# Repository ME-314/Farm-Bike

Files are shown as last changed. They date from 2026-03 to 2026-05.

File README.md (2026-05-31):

# Farm-Bike
## Preamble
A simultaneous engineering project at EPFL under the *Durabilité* unit, which aims to create a modular power source for various farm machinery utilizing human work as the source of power. The development of this machine is the work of a whole semester. The project describes every step from design to machining and testing. 
<table>
  <tr>
    <td></td>
    <td></td>
  </tr>
</table>
The machine built has successfully fulfilled the requirements outlined in the subsequent paragraphs, multiple farming implements were also retrofitted to be compatible with it. Testing showed promising results and the modularity of the design proved indispensable.  

The CAD models for this project can be found in the *CadParts* folder and the manufacturing and assembly drawings in the *Drafts* folder. The *Design* section shows general design intent and is aimed at anyone wanting to recreate as similar design or better understand this one. Meanwhile the *Manufacturing* section describes the most interesting challenges faced during the fabrication of this prototype. The safe operation of machinery used requires training that this document doesn't provide. For this reason the *Manufacturing* section is not a guide and omits operations that are trivial to readers familiar with metalworking. This section is intended to provide ideas on the order of operations or fabrication techniques.  Necessary processes are specified per part to help evaluate the feasibility in accordance with available resources   

The following README contains information that may overlap with other documentation contained in the repository but is not intended as a replacement for those documents. 

<a href="https://github.com/ME-314/Farm-Bike">ME-314 Farm-Bike</a> © 2026 by Alex Baptista Coelho, Simon Dalheimer, <a href="https://github.com/FSzymans">Franciszek Szymanski</a> and Jules Taramarcaz is licensed under <a href="https://creativecommons.org/licenses/by-nc-sa/4.0/">CC BY-NC-SA 4.0</a>



## Project Video

A short video presentation of the Farm-Bike project has been published on YouTube. It shows our work atmosphere, talks about the design choices and the manufacturing process of the bike, and shows a little bit of the testing preformed at the Bassenges farm.

The video can be watched here: [Farm-Bike Project Video](https://youtu.be/_lzx3uVPyf8)

## Specification 
#### Functionality 
The Farm-Bike prototype was designed to fulfill the following main functional requirements:

- Provide a way of converting human power into useful shaft work.
- Have an easily adjustable transmission ratio.
- Allow for quick coupling with multiple machines.

In addition to these functional requirements, several quantitative design assumptions were used to dimension the prototype:

- The Farm-Bike was designed for an adult operator with a cycling cadence of `n = 70 rpm` and a continuous mechanical power input of `P = 250 W`. A considerable safety factor was also taken into consideration.
- The coupled farm machines considered during the project were assumed to operate at relatively low rotational speeds: `50–150 rpm`.
- Ergonomic parameters, such as saddle height, handlebar position, and frame geometry, were chosen to be adjustable so that users of different sizes can pedal comfortably.
#### Work Environment 
- Resist an outdoor work environment subject to a central European climate
- Resist storage in wet conditions
#### Durability
- Be built wherever possible out of standard parts to ensure long term parts availability
- Machined component to only use conventional machining to provide possibility of field repair
- Use of quality components to ensure a long life cycle  
- Easy maintenance procedures
## Design 
The design of the machine was driven by the specification outlined above and the will to ensure the project can be replicated or further developed in the future. The design choices are driven by the will to create a machine that has a long service life, quality parts and materials were chosen over low-cost alternatives.

For the final coupling between the Farm-Bike and the driven machine, a v-belt transmission was selected. This design choice provides a simple and flexible mechanical interface between the machines. Compared with a rigid shaft coupling, a belt drive is easier to install on existing agricultural machines and is more tolerant to small positioning and alignment errors. It also allows the Farm-Bike to remain mechanically independent from the driven machine, making the system easier to transport, reposition and adapt during usage. From a design point of view, the belt stage also contributes to the transmission ratio: by changing the pulley diameters, the output speed and torque can be adapted to different machines without modifying the bicycle drivetrain itself. Finally, belts and pulleys are standard, inexpensive components, which supports the project goals of repairability, modularity and long-term reproducibility.

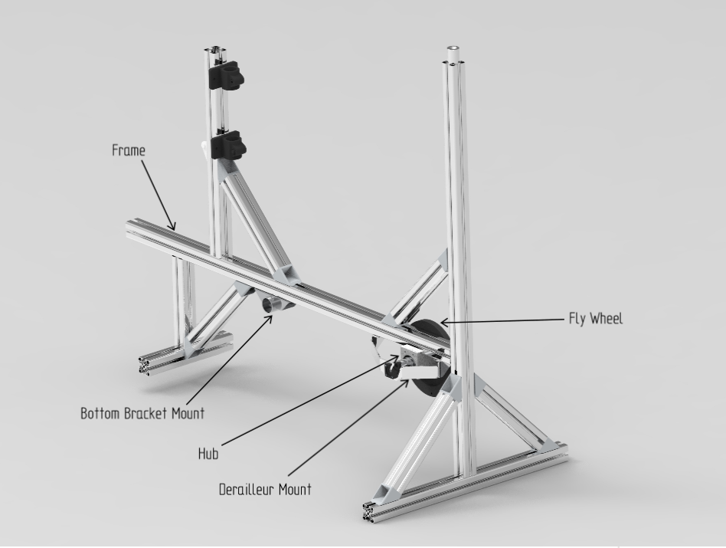
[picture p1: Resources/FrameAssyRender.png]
Render of the machine


The render above outlines the key components of the machine.
### [Frame](https://github.com/ME-314/Farm-Bike/blob/main/Drafts/FrameAssembly.pdf)
The frame is made out of Item modular aluminium extrusions, specifically the profile 8 series. This made the construction of the frame simple and required only off-the-shelf parts. The Item profile 8 can be substituted by any equivalent 40 mm $\times$ 40 mm T-slot aluminium extrusion. These dimentions correspond to a common industrial 
T-slot aluminium profile size. It was specifically chosen as a compromise between stiffness, 
weight and availability. Smaller profiles, such as 20 mm $\times$ 20 mm or 
30 mm $\times$ 30 mm, are commonly used for light frames or small mechanical 
assemblies, but would provide less bending and torsional stiffness for a structure supporting 
a seated operator and transmitting pedalling loads. Larger profiles, such as 40 mm $\times$ 80 mm 
or 80 mm $\times$ 80 mm, would increase stiffness but would also make the structure heavier, 
more expensive and less practical to handle. 

The 40 mm $\times$ 40 mm profile therefore offers a suitable intermediate solution for this 
prototype. It is widely used in modular machine frames and workstations, and it is compatible 
with standard T-slot accessories such as brackets, corner connectors, end plates and sliding 
nuts. In addition, all the aluminum profiles were recovered from the SPOT workshop at EPFL and have been used in previous projects before ours.
### Drivetrain
A transmission based on bicycle components is an optimal off-the-shelf solution to our problem. It offers robustness, ease of maintenance and worldwide availability at a low cost. The following components in the system required no modification from their retail configuration: 
- Cassette 
- Derailleur & Shifter
- Handlebars & Stem
- Crank set & Bottom Bracket
- Seat post & Saddle 

The machine is designed to be used as a modular power source for various farming implements, many of which are hand cranked and operate at around 60 rpm. Gear ratios of the bicycle drivetrain and the sizes of the pulleys were chosen in a way that allows the operator to adjust the rotational speed up and down without stopping the machine. 

The subsequent paragraph describe the design of each of the machine specific parts. The parts were designed to conform with bicycle industry standards such that commissioning and maintenance could be carried out by anyone familiar with common bicycles.

#### Gear Ratios Calculation
With the chosen cassette and chainrings and an assumed cadence of 70 rpm the output of the machine can vary between 47 and 137 rpm. If necessary the size of driven pulley mounted to the farming implement can be adjusted to suit. To simplify adapting other machinery and further development the ratio calculation spreadsheet is available in the documentation.

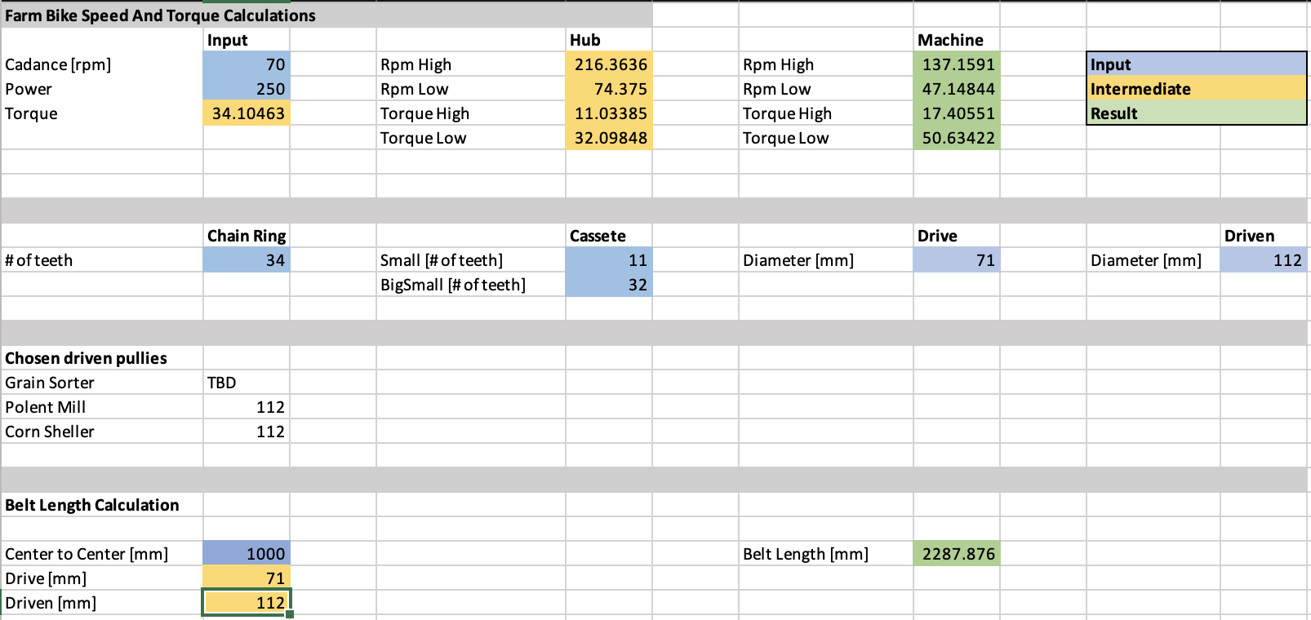
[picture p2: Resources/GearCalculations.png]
Ratio Table


For the currently selected driven pulley diameter of 112 mm, this range covers the operating speed of the polenta mill and corn sheller used during testing. In the spreadsheet you can also see a centre-to-centre distance of 1000 mm, which gives an estimated belt length of approximately 2288 mm for the 71 mm and 112 mm pulley pair.

#### Bottom Bracket Shell
The bottom bracket shell attaches the standard BSA bicycle bottom bracket to the frame. The part is a weldment of a round bottom bracket shell recovered from a donor frame and a 40 mm $\times$ 30 mm rectangular steel tube (since this part was recovered from an existing bike frame, its dimensions have not been chosen by us and were imposed by the donor frame, so standard bike components and dimensions). The part requires far less material resources than an equivalent machined from a billet and does not require specialty tooling to cut the BSA thread. By clicking this [link](https://github.com/ME-314/Farm-Bike/blob/main/Resources/BBS_removal.MOV), you can see how the part was recovered, separated from the frame and cleaned for our requirements (frame on the left of the video and BBS clamped on the table).
#### Hub
The hub forms a central part of the transmission of the machine, it mounts the cassette and the pulley thus transmits all of the power generated. A flywheel is also mounted on the axle to smooth out the power delivery.  
##### Pillow Block

This part houses the main bearings and attaches to the frame. It is a crucial part that maintains the alignment between that two bearings and ensures their long life and smooth operation, for this reason it is machined out of a 6061 Aluminium billet. Due to unavailability of appropriate stock the pillow block has been split into two pieces and pinned together. It features clearance holes for two M8 mounting bolts, a central bore for the axle to pass through and two counterbores for the 6005-2Z bearings. These deep groove ball bearings have been selected to ensure a long life span as well as being easy to source. Low-profile ball bearing often found in bicycles have specifically been discarded as their lower profile makes them more prone to premature failure. A recess has been added at the mounting between the pillow block and the aluminium profile to prevent twisting during usage.

##### Axle
The large bearings allow us to use an aluminium axle without risking the keyway becoming fragile. The axle features 25 mm bearing seats and a key way to transmit torque to the flywheel and pulley. In order to mount the cassette onto the axle while avoiding complex machining operations a donor freehub body was bonded onto the axle. The axle was of course designed around the specific freehub body available thus the design would need to be modified in accordance with available parts. 
#### Derailleur Hanger
To emulate the derailleur mounting of a conventional bicycle without having to cut a fine pitch thread a derailleur hanger from a donor frame was utilized. In order to correctly position it with respect to the axle and cassette a mount was designed out of 3mm 5005 aluminium sheet. The mount exploits the advantages of bent sheet metal to achieve a robust yet lightweight solution. 
## [Manufacturing](https://github.com/ME-314/Farm-Bike/blob/main/Drafts/FarmBikeAssembly.pdf) 
This section outlines the manufacturing processes of each of the parts and provides photos of the components. It assumes the reader is comfortable with conventional machining processes and general fabrication and thus omits the details of most trivial operations. Some parts in the assembly are overlooked in this section as their manufacturing features no operations of interest.
### [Bottom Bracket Shell](https://github.com/ME-314/Farm-Bike/blob/main/Drafts/BBMount.pdf) 
- TIG Welding
- Turning 

This is the only weldment on the machine, consisting of two parts with thin sections. The donor frame was chosen for its steel construction and BSA threaded bottom bracket. The shell was cut out and turned down to a constant diameter. During the turning operations a close fitting aluminium plug was used on the inside of the threads to provide tailstock support. The hole for the shell in the rectangular tubing was roughed out with a hole saw on a mill and fitted by hand with a file. The two parts were subsequently TIG welded and the thread was chased. TIG welding was used because of the thin material and in order to preserve as much of the BSA thread inside the shell.  

It should be noted that a farmer is not necessarily expected to have access to TIG welding equipment. A future version could therefore replace this welded part with a clamped or bolted bottom bracket support, removing the need for welding and making the design easier to reproduce with basic tools.
<table>
  <tr>
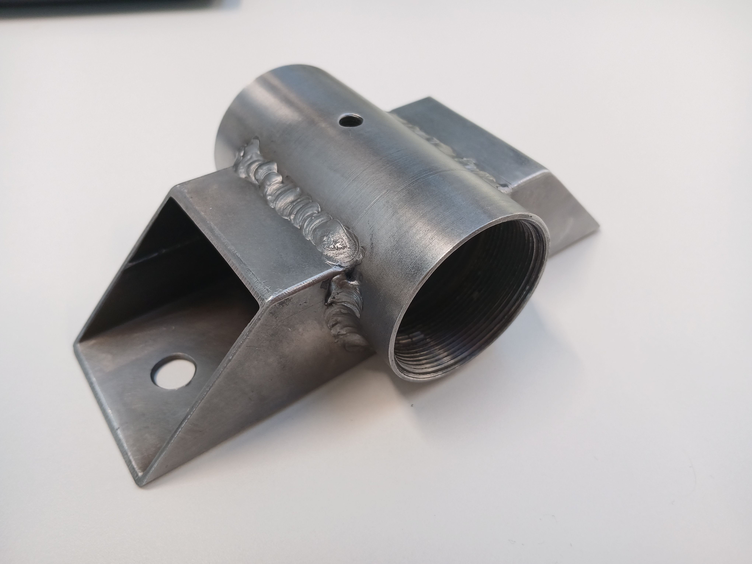
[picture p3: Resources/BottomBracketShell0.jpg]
    <td></td>
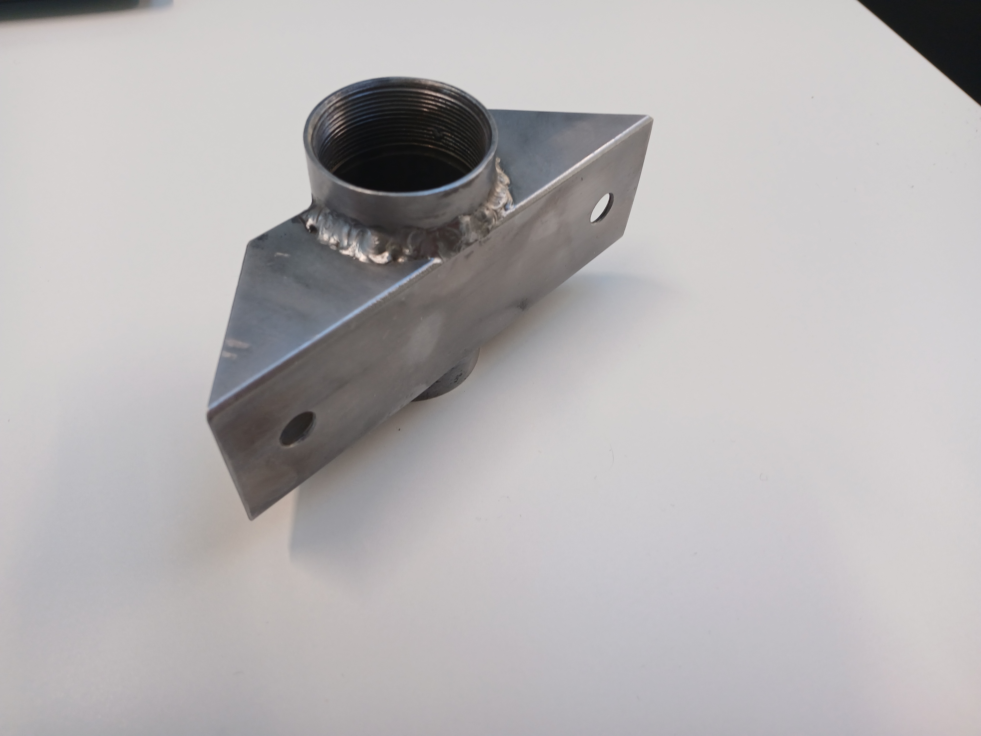
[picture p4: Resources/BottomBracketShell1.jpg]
    <td></td>
  </tr>
  <tr>
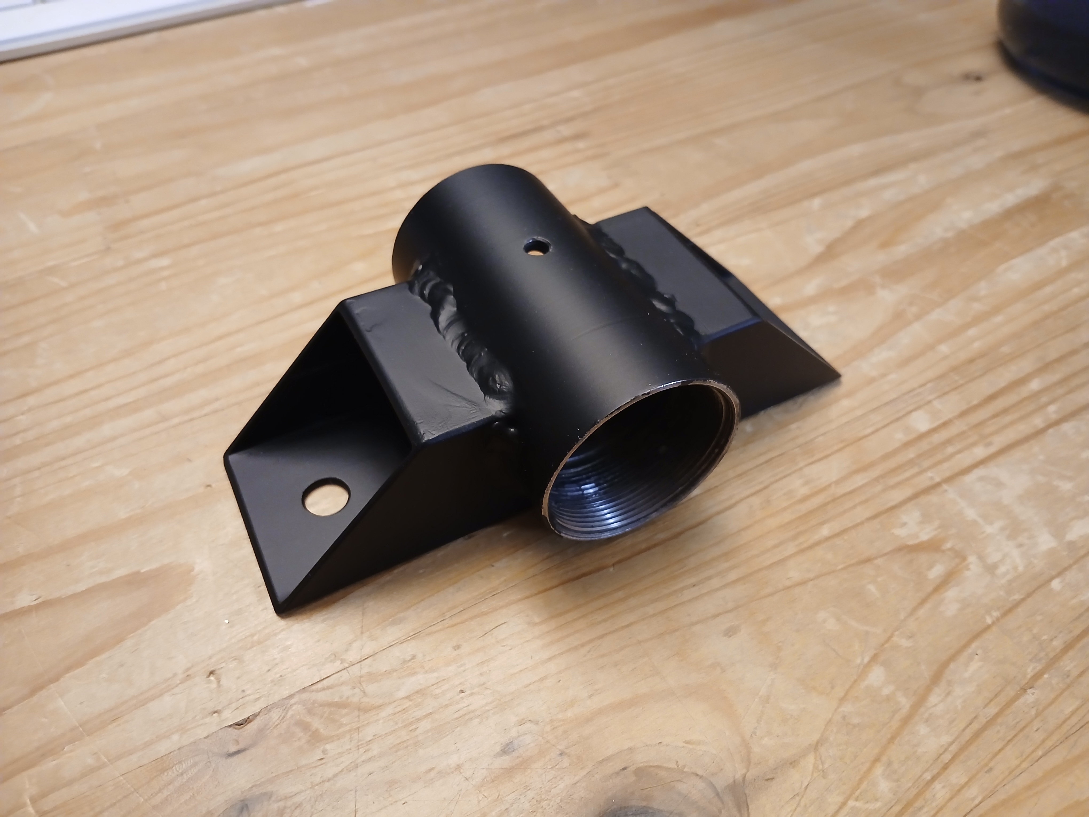
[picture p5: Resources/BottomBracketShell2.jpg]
    <td></td>
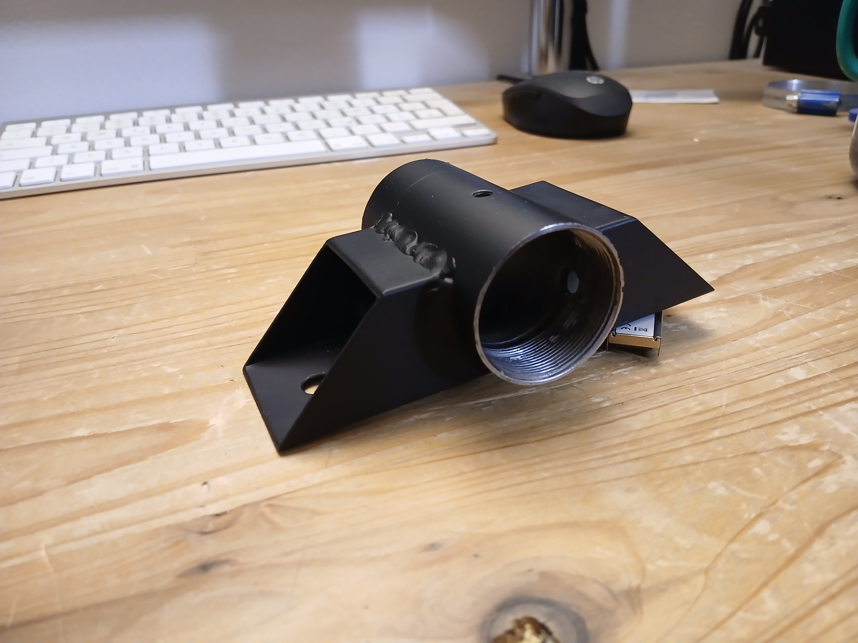
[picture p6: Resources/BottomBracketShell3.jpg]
    <td></td>
  </tr>
</table>
After welding, the oxides were removed and the part was finished with automotive anti-rust primer. 

### [Axle](https://github.com/ME-314/Farm-Bike/blob/main/Drafts/DriveAxle.pdf)
- Turning 
- Milling

The machining operations did not deviate from standard practice. Loctite 603 retaining compound was used to chemically bond the freehub body to the axle. Chemical bonding was chosen to remove the need for pressing in the axle thus eliminating the risk of fracture on the hardened freehub body. 
### [Pillow Block](https://github.com/ME-314/Farm-Bike/blob/main/Drafts/PillowBlock.pdf)
- Turning 
- Milling
Due to limitations in the available stock material the pillow block was machined from two separate pieces of stock.

Watch the video

The operations were carried out in the following order: 
- Squaring the stock to size 
- Drilling and reaming of the 4mm pin bores
- Centre drilling of the main bore
- Two parts are pressed together 
- Milling locating slot 
- Drilling of two M8 clearance holes
- Boring half of the through bore in a lathe with centre drill hole as reference
- Boring of bearing seat
- Part flipped and boring operations repeated
- Deburring and chamfering 

<table>
  <tr>
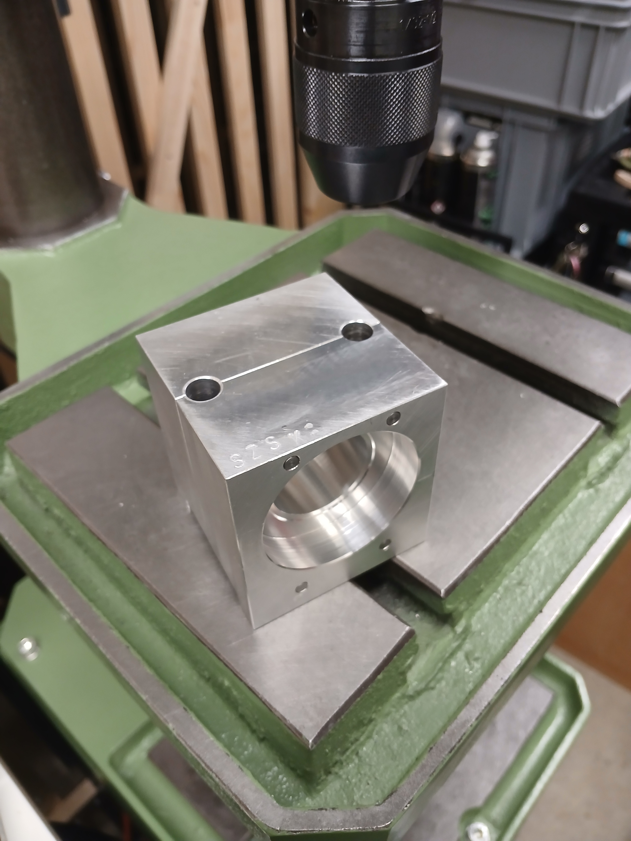
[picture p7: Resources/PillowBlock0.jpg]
    <td></td>
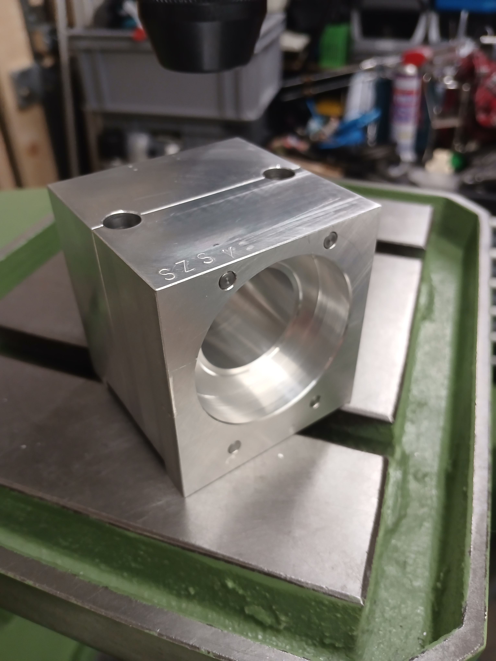
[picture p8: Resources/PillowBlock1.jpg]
    <td></td>
  </tr>
  <tr>
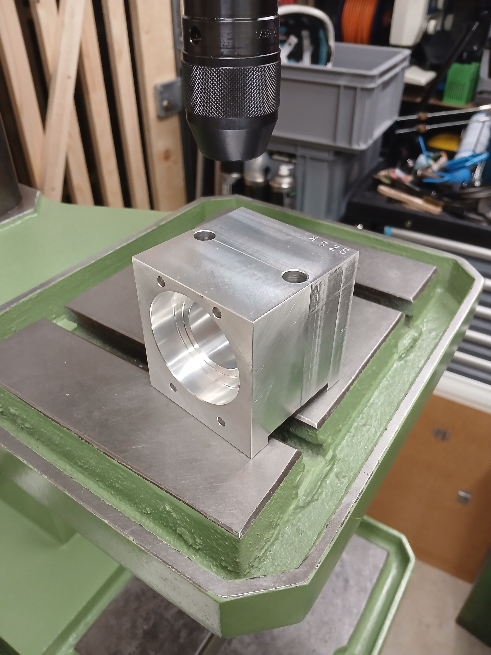
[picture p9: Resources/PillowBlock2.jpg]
    <td></td>
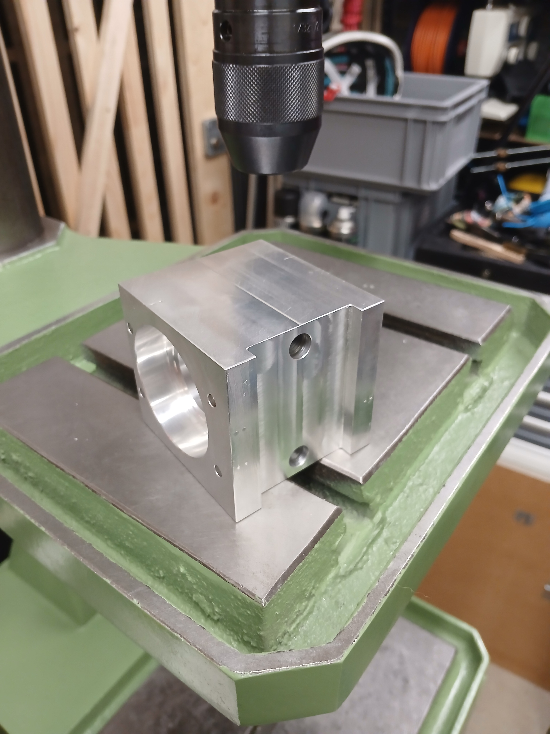
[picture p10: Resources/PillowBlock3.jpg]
    <td></td>
  </tr>
</table>
Following machining, deburring and finishing was carried out and the bearings were fitted

### [Fly Wheel](https://github.com/ME-314/Farm-Bike/blob/main/Drafts/FlyWheelAssyDrawing.pdf)
- Turning 
- If available fibre laser cutting or water jet

In order to avoid procuring costly stock material the fly wheel is cut out of 5 mm S235 structural steel (a bit pedantic of a designation, we know, but what is life without whimsy) and the pieces are pinned together. The use of a fibre laser allows for significant time saving but all of the parts can be machined using conventional processes. Our parts were pressed together with an arbor press and a coat of anti-rust primer protects against corrosion. Since the flywheel geometry is relatively simple, the plates could also be manufactured using more accessible workshop methods: drilling combined with sawing, or even manual cutting followed by filing and balancing.
<table>
  <tr>
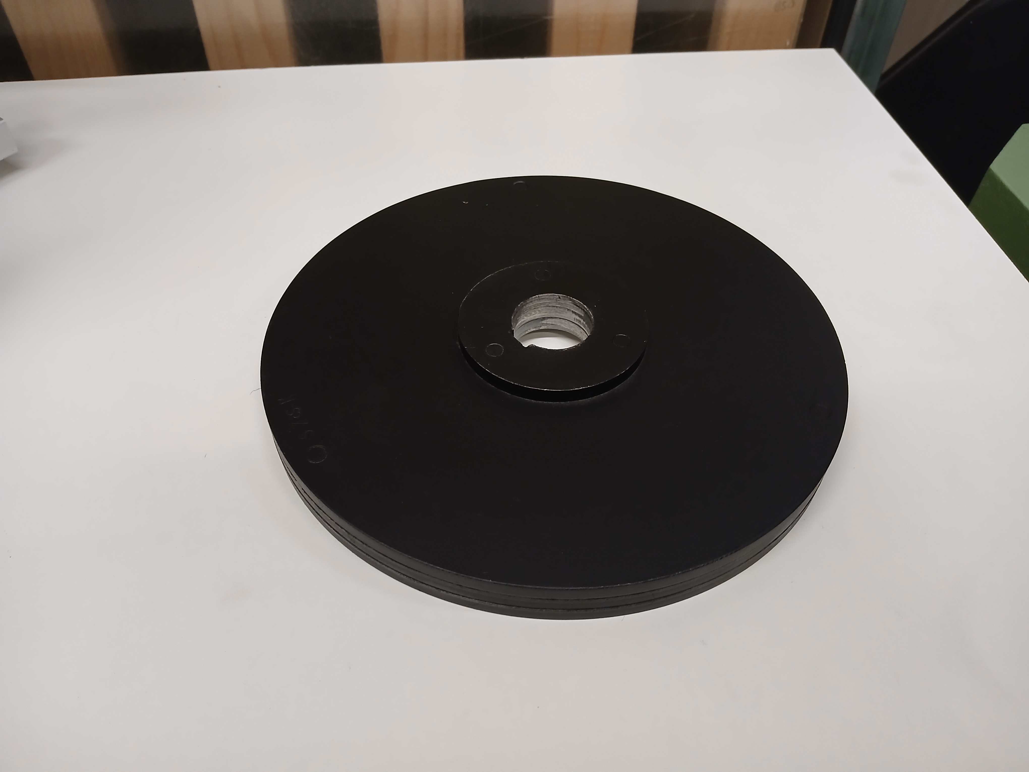
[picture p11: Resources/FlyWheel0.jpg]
    <td></td>
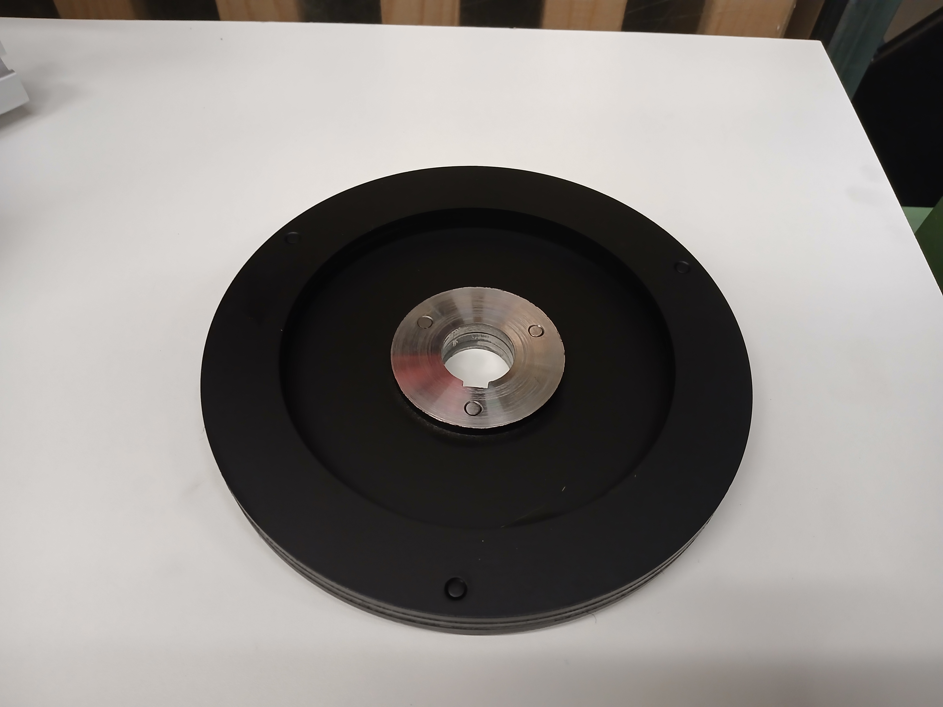
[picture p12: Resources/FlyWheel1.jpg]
    <td></td>
  </tr>
</table>

### [Hub](https://github.com/ME-314/Farm-Bike/blob/main/Drafts/HubExploded.pdf) 
Precaution taken during assembly of the hub:
- Parts cleaned and lubricated 
- Light preload applied to the bearings 
- Taper lock pulley and bushing torqued to manufacturer specification

<table>
  <tr>
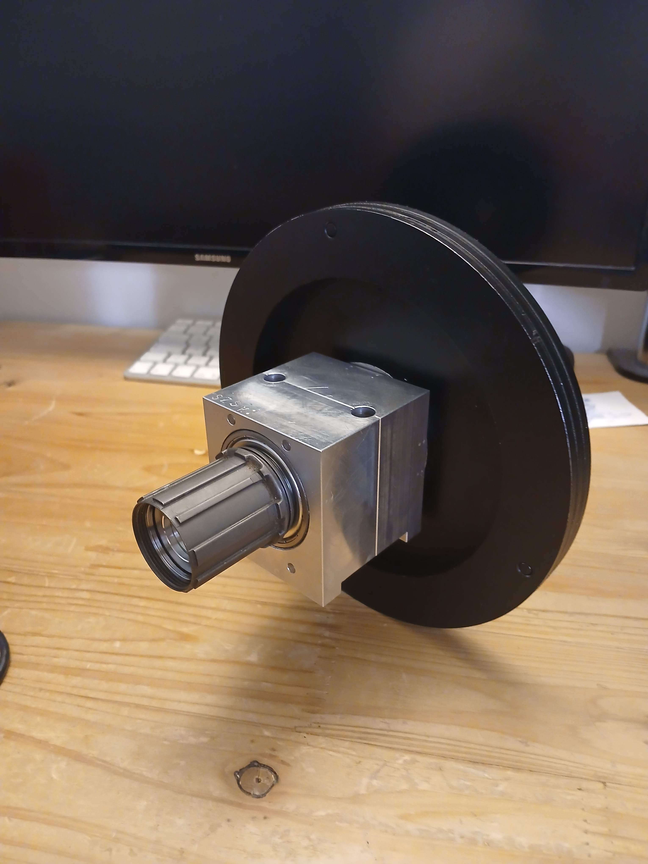
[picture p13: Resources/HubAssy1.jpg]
    <td></td>
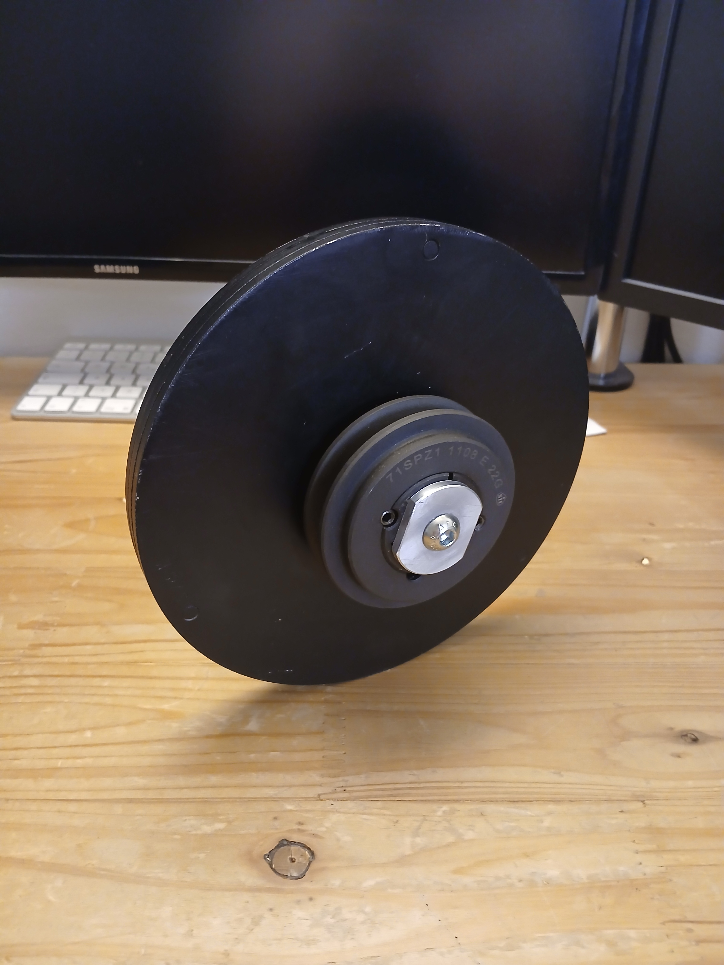
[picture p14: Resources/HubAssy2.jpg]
    <td></td>
  </tr>
</table> 

### [Derailleur Mount](https://github.com/ME-314/Farm-Bike/blob/main/Drafts/DerailleurBracketDrawing.pdf) 
- Metal Cutting
- Sheet Metal Bending
- If available fibre laser cutting or water jet

Just like the fly wheel the derailleur mount was cut with the use of a fibre laser. Due to its non-trivial geometry the sheet metal part was bent in a bench vice with the help of parallel jaw pliers. The existing derailleur hanger was hand fitted during the finishing process. As most of the part geometries are non mating surfaces the part could be replicated with hand tools. The geometry can be modified to suit the manufacturing methods available.
<table>
  <tr>
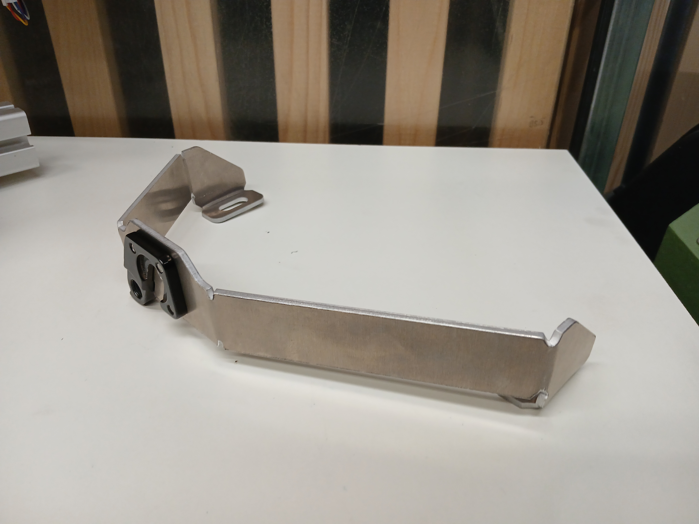
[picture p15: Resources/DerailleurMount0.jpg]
    <td></td>
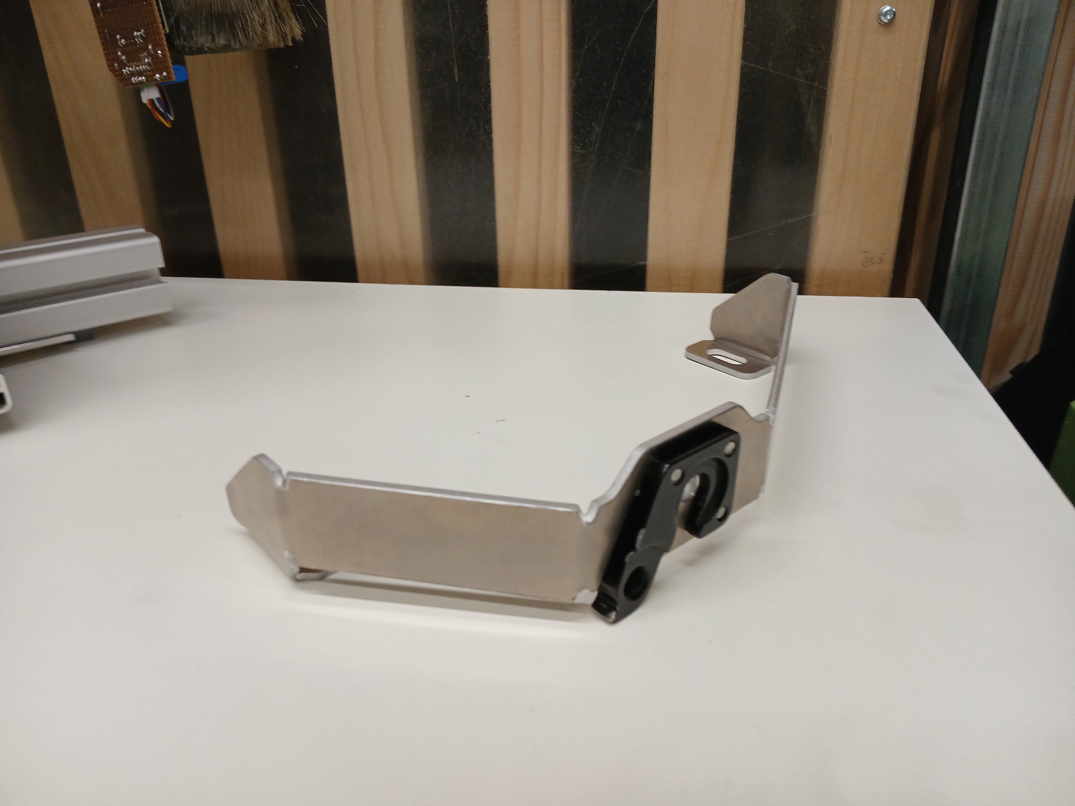
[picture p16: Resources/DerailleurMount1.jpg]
    <td></td>
  </tr>
  <tr>
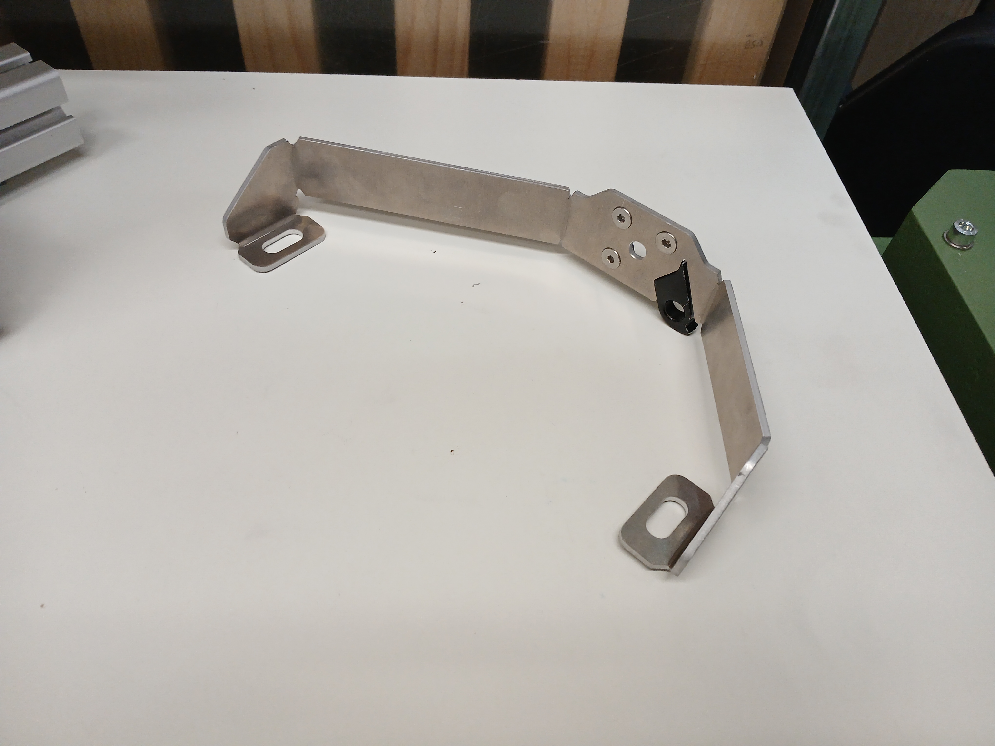
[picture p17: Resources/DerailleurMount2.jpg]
    <td></td>
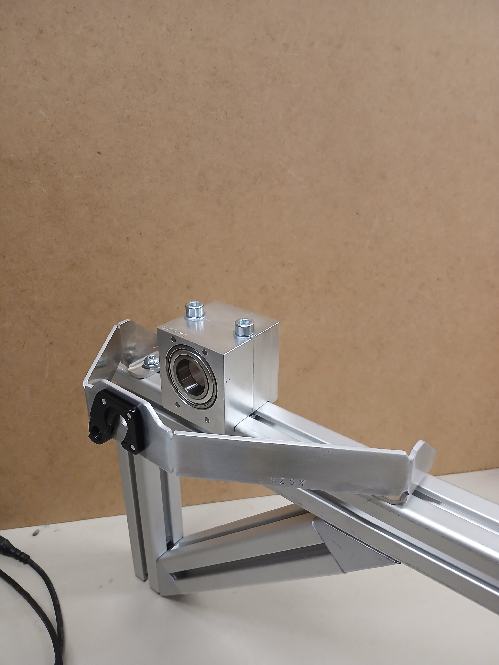
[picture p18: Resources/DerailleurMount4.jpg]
    <td></td>
  </tr>
</table> 

## Procurement Guide 
Normalized industrial parts for this project can be commonly bought new from well established suppliers. The parts for the prototype were sourced from [Norelem](https://www.norelem.ch/), but equivalent parts can be sourced from: 
- [Misumi](https://fr.misumi-ec.com/)
- [RS Components](https://us.rs-online.com/)
- [McMaster-Carr](https://www.mcmaster.com/)
- [JLCMC](https://jlcmc.com/)
In this project the part numbers specified on assembly drawings and in the cad model correspond to Norelem part numbers.  
To reduce the ecological impact of the prototype, second hand or recovered components were utilized in areas that would not impact the longevity, safety or operation of the machine.
Item aluminium profiles and relevant hardware were recovered from decommissioned machinery. Equivalents can be sourced from the suppliers above or Item24 directly. Wherever possible material off-cuts or scrapped parts we used as stock material.   
Bicycle components for the prototype were second hand and sourced from *Point Vélo* located on the EPFL campus.

## Prototype Overview

After the design and manufacturing phases, the **Farm-Bike prototype** was fully assembled.

The image below shows the assembled Farm-Bike prototype in its final pre-testing configuration. It highlights the complete mechanical structure, including the aluminium frame, the bicycle transmission, the rear wheel 10-speed cassette, the pedals, and the operator interface.

<p align="center">
  Assembled Farm-Bike prototype in pre-testing configuration
</p>

<p align="center">
  <em>Assembled Farm-Bike prototype.</em>
</p>

This final assembly represents the functional outcome of the project and serves as the basis for future improvements, such as ergonomic optimisation, stronger machine coupling, and further field testing at the farm.

## User Guide 

### Use Instructions 
Before operating the machine, ensure that it is placed on a stable and level surface. The frame should not rock or move under load, and all fasteners securing the aluminium profiles, pillow block, bottom bracket shell, seat post and handlebar assembly should be checked for tightness. The pulley, flywheel and cassette should be visually inspected to ensure that they are correctly seated and that no foreign object is interfering with the drivetrain.

The user should adjust the saddle height and handlebar position to obtain a comfortable pedalling position. As with a conventional bicycle, the saddle height should allow the leg to remain slightly bent at the bottom of the pedal stroke. The drivetrain can then be shifted using the standard bicycle shifter in order to select the desired transmission ratio. The rear derailleur can be shifted using the standard handlebar shifter, while the front chainring selection has to be carried out manually. The user should therefore stop pedalling, wait for the drivetrain to come to rest, and move the chain by hand only when the machine is fully stationary. This should be done by getting off the bike, adjusting the chain to the desired chainring setting and gently cranking the pedals by hand such that the chain jumps into its desired place. The user can afterwards get back onto the bike and pedal normally. Lower gears should be used when starting the machine or when driving a high-load implement, while higher gears can be used once the system is already rotating smoothly or when a higher output speed is required.

To start the machine, the user should begin pedalling progressively and avoid sudden impacts on the pedals. The flywheel will gradually store kinetic energy and smooth out the power delivery. Once the machine is rotating steadily, the selected gear ratio can be adjusted depending on the required output speed and the resistance of the coupled machine. Gear changes should preferably be carried out while pedalling with moderate force, in the same way as on a standard bicycle, in order to avoid excessive stress on the chain and derailleur.

Before coupling the Farm-Bike to an external machine, the user must ensure that the driven machine is compatible with the output speed, torque and rotation direction of the system. The coupling should be securely mounted and aligned with the pulley or output shaft to avoid vibrations, belt slipping or premature wear. During operation, hands, clothing and loose objects must be kept away from the chain, cassette, pulley, flywheel and any rotating element.

To stop the machine, the user should simply reduce pedalling effort progressively and allow the drivetrain and flywheel to slow down naturally. The user should not attempt to stop the flywheel, pulley or chain by hand. After use, the machine should be inspected for loose fasteners, abnormal noise, chain misalignment or signs of wear. If the machine has been used outdoors or stored in humid conditions, exposed steel parts should be dried and checked for corrosion.

### Maintenance Guide 
Time intervals for preventative maintenance intervals are guidelines, maintenance intervals should be adjusted in accordance with conditions of use and storage. 
- each use inspect fasteners and drivetrain
- 7-10h clean and lubricate chain
- 30-50h degrease and lubricate chain
- 100h inspect drivetrain for wear
- 150h disassemble and inspect hub and crank set

Parts deemed inoperable during inspection are to be replaced 

For a more detailed explanation on fitting adjusting and maintaining bicycle specific components please refer to General Operations Manual *(ref:DM-GN0001)* published by Shimano.

### Troubleshooting Guide  

| Issue | Likely cause | Corrective action |
|---|---|---|
| Unusual noise | Loose fastener | Verify and tighten fasteners. |
| Chain skips under power | Worn drivetrain components | Replace the chain. If the issue persists, replace the cassette and chainrings. |
| Chain jumps between gears | Shifting not adjusted | Adjust the shift cable. |
| Chain falls off the top or bottom of the cassette | Derailleur limits out of adjustment | Adjust the derailleur limits. |
| Excessive friction in drivetrain under no load | Debris stuck or tangled in the drivetrain | Inspect the drivetrain and remove debris. |

## Testing 

### Initial Testing

The first functional test was carried out directly at the Bassenges farm. The Farm-Bike prototype was brought to the farm and connected to two existing machines: the polenta grinder and the corn sheller. Pulleys were installed on both machines, after which the bike was coupled to the system and tested. The first test was successful, as the Farm-Bike was able to drive the machines through the belt transmission. The whole Bassenges team was present during the test.

However, once the system was operating, an important ergonomic issue was identified by Timothée, the farmer responsible for following the project at the Bassenges farm. In the initial configuration, the bike was not facing the machines. This meant that a single operator could not comfortably pedal the bike and load the machines at the same time. This feedback highlighted an important practical limitation of the first assembly.

After considering the problem, we realized that the modular aluminium profile frame made it possible to rearrange the bike without manufacturing new parts. Several components were repositioned so that the pulley attachment faced the opposite direction and was located at the front of the bike. This allowed the Farm-Bike to be adapted directly to the farmer's request. Due to the lack of equipment at the farm, we were not able to reduce the length of the chain, which is planned for the following week.

Initial testing confirmed the value of using modular aluminium profiles for the frame. The ability to modify the geometry of the machine on site was a major advantage during the testing phase. If the frame had been fully welded or made as a fixed steel structure, this last-minute correction would not have been possible without significant rework.

The following images show the Farm-Bike before and after the reassembly:

<table>
  <tr>
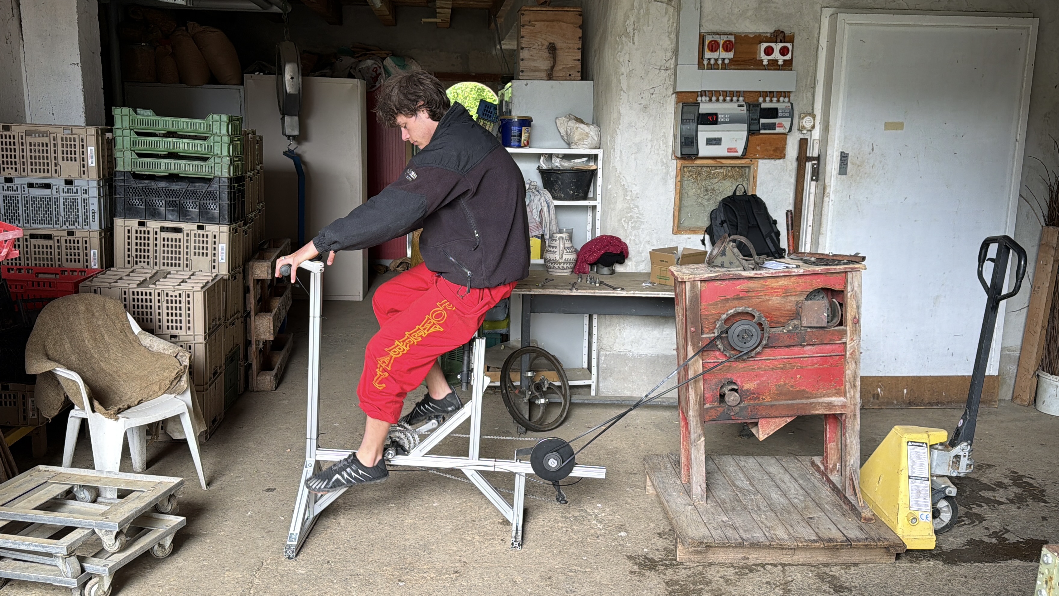
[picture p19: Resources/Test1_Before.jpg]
    <td></td>
    <td></td>
  </tr>
  <tr>
    <td align="center"><em>Initial configuration</em></td>
    <td align="center"><em>Modified configuration</em></td>
  </tr>
</table>

### Second Testing Session

The second day of testing allowed the team to further adapt the **Farm-Bike prototype** based on the observations made during the first trial.

In particular, the chain length was adjusted and the seating position was modified accordingly. The overall design proved to be functional; however, the shortening of the chain had an effect on the shifting performance. Gear changes became less smooth than before, and the most extreme gear-ratio settings became more difficult to use.

Another important feedback point was given by **Timothée**, who suggested keeping the inertial wheel attached to the corn sheller. In response to this, the pulley transmission was modified. Instead of removing the inertial wheel, the pulley system was attached to the rear side of the transmission axle, replacing an old unused gear. This allowed the inertial wheel to be reinstalled on the machine while still maintaining the connection between the Farm-Bike and the corn sheller.

The following day, the team returned to the farm to make additional ergonomic and functional improvements. The shifting cable was shortened, and the stem was lengthened in order to improve both the shifting accessibility and the seating position. These modifications made the system more comfortable to operate and better adapted to the user during testing.

The image below shows the Farm-Bike connected to the corn sheller during the testing phase.

<p align="center">
  Farm-Bike prototype connected to the corn sheller during testing
</p>

<p align="center">
  <em>Farm-Bike prototype connected to the corn sheller during testing.</em>
</p>

### Last Testing Session

During the final week of testing, an interview was conducted with Timothée as part of the video presentation of the project. The discussion focused on his feedback regarding the Farm-Bike prototype, his impression of the proposed solution for driving the machines, and the possible improvements he suggested for future iterations.

One improvement mentioned by Timothée was to make the system compatible with flat belts. This suggestion was based on the fact that many agricultural machines from the early twentieth century were originally designed to be driven by flat belts. In addition, flat belts can be easier to manufacture or repair locally, for example from leather or other flexible materials that can be cut to the required width and length.

During this final testing phase, a third pulley system was also installed on a grain sorter. This machine was different from the agricultural machines analyzed previously, which allowed the adaptability of the Farm-Bike concept to be further evaluated.

Here is the grain sorting machine shown below. This machine already includes a mechanical transmission system, making it suitable for coupling through an external belt drive.

<p align="center">
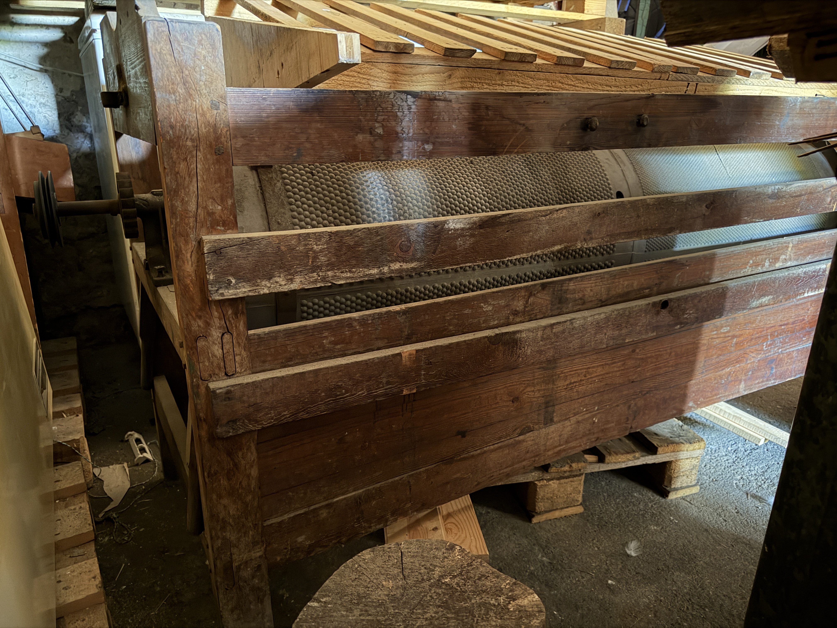
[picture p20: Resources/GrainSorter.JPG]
General view of the grain sorting machine
  
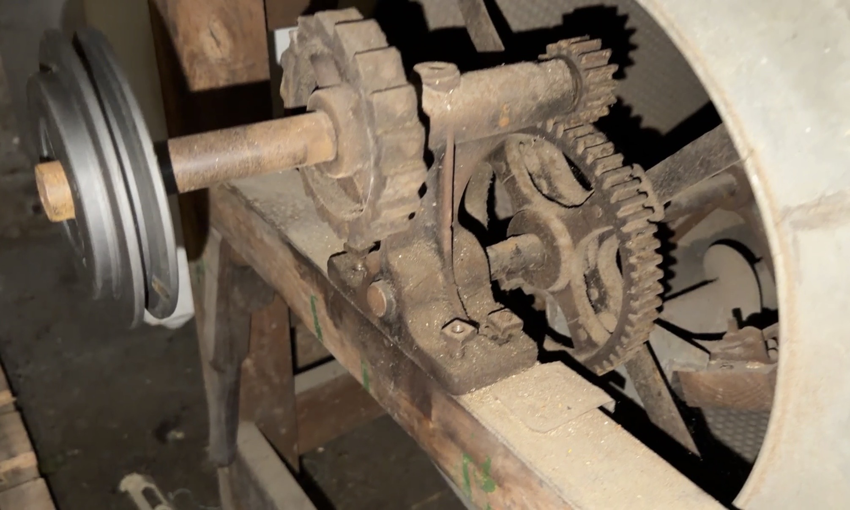
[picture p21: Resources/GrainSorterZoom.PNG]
Close-up view of the pulley and gear mechanism
  
</p>

<p align="center">
  <em>Existing grain sorting machine and close-up view of its pulley and gear transmission mechanism.</em>
</p>

## Conclusion & Future Improvements

A future improvement identified during the final testing phase would be to make the Farm-Bike compatible with flat belt transmissions. Timothée pointed out that many older agricultural machines, were originally designed to be driven by flat belts. Adding this compatibility would therefore increase the number of machines that could be powered by the Farm-Bike, especially in the context of farms using older or restored equipment.

This improvement would require the development of an alternative output pulley system designed specifically for flat belts. The pulley geometry, belt tensioning method and alignment system would need to be adapted, since flat belts are more sensitive to lateral misalignment than V-belts. However, this solution would also improve the repairability and local reproducibility of the system, as flat belts can be manufactured or repaired more easily from simple flexible materials, such as leather or rubber strips cut to the required width and length.

More generally, this feedback shows that future development should focus not only on the Farm-Bike itself, but also on the compatibility between the bike and a wider range of agricultural machines. A modular output interface, with interchangeable pulleys for V-belts and flat belts, would make the system more versatile and better adapted to real farm conditions.

## List of Components & Costs

### STEP Assembly File Component List

The following table lists the main components from the `FarmBike.stp` assembly with the respective names used.

| Quantity | Component name |
|---:|---|
| 10 | 45Joint |
| 6 | FrontSupport |
| 2 | TubeClampMount |
| 2 | 6005-2Z bearing |
| 2 | PillowBlock |
| 2 | 29014-30 |
| 2 | FlyWheelMass |
| 2 | FlyWheelSpacer |
| 1 | HeadTube |
| 1 | MainFrame |
| 1 | 23200-0382522 |
| 1 | 22070-12711 |
| 1 | FreeHubBody |
| 1 | FrontLeg |
| 1 | DerailleurBracket |
| 1 | 27616-08095 |
| 1 | StemMount |
| 1 | BackSupport |
| 1 | BottomBracketMount |
| 1 | BottomBracketShell |
| 1 | FilletWeld_1 |
| 1 | DerailleurHanger.psm |
| 1 | SeatTube |
| 1 | FlyWheel |
| 1 | DriveAxle |
| 1 | DummyBearing |

### Aluminium Profile Cut List

The main frame is made from 40 × 40 mm aluminium profile. The total required profile length is approximately **4.96 m**.

| Quantity | Component | Profile type | Length per part | Total length |
|---:|---|---|---:|---:|
| 1 | HeadTube | 40 × 40 mm aluminium profile | 1000 mm | 1000 mm |
| 1 | MainFrame | 40 × 40 mm aluminium profile | 1160 mm | 1160 mm |
| 6 | FrontSupport | 40 × 40 mm aluminium profile | 250 mm | 1500 mm |
| 1 | FrontLeg | 40 × 40 mm aluminium profile | 580 mm | 580 mm |
| 1 | BackSupport | 40 × 40 mm aluminium profile | 220 mm | 220 mm |
| 1 | SeatTube | 40 × 40 mm aluminium profile | 500 mm | 500 mm |
|  | **Total** |  |  | **4960 mm** |

### Components Purchased from Point Vélo

The following bicycle components were purchased from Point Vélo and used for the Farm-Bike drivetrain and rider interface.

| Quantity | Component |
|---:|---|
| 1 | 10-speed cassette |
| 1 | Pair of pedals |
| 1 | 3-speed chainring / crankset |
| 1 | Rear derailleur |
| 1 | Saddle |
| 1 | Seatpost |
| 1 | Stem |
| 1 | Handlebars |
| 1 | Bottom bracket shell |
| 1 | 10-speed compatible chain |
| 1 | Rear derailleur shifter |
| 1 | Set of shifter cables |

### Farm-Bike Budget Sheet — Confirmed Purchases

<p align="center">
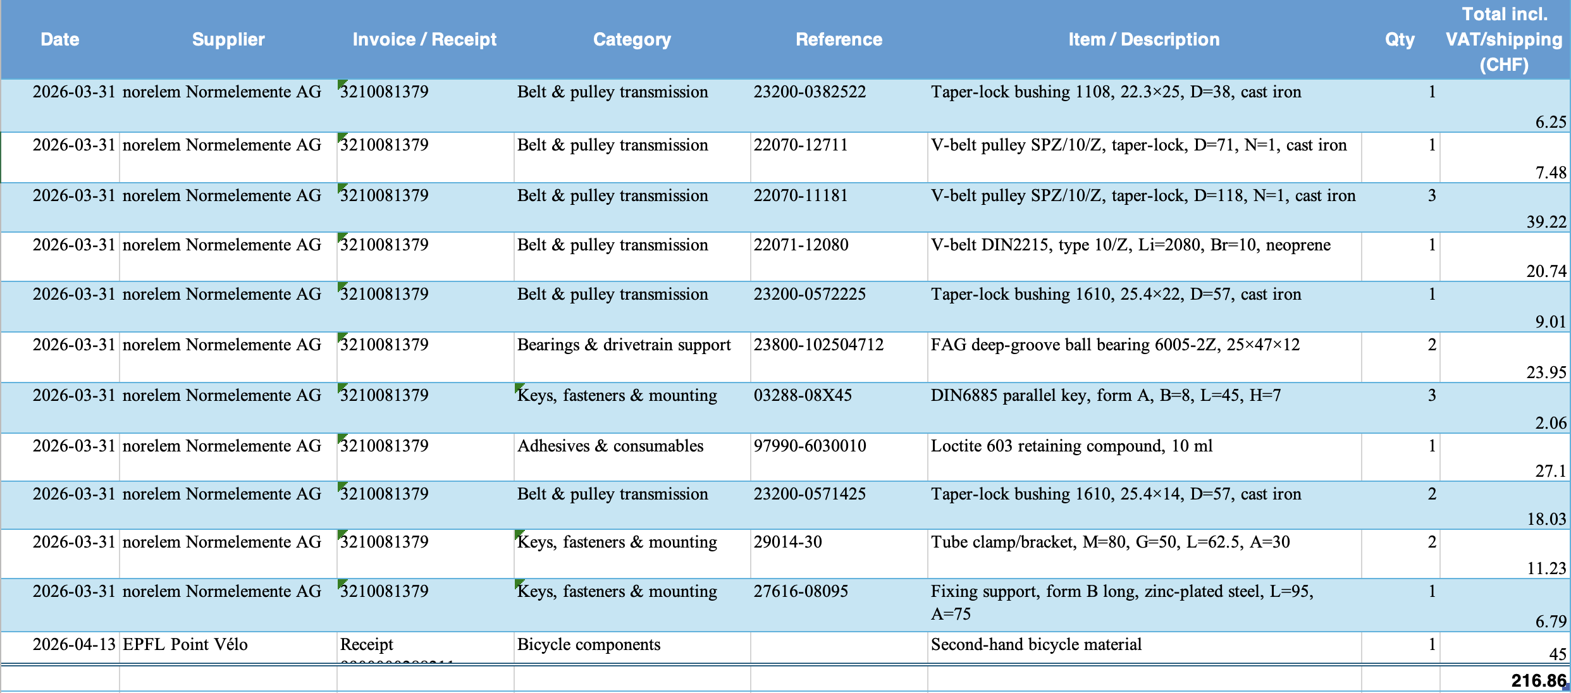
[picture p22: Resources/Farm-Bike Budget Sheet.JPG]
Confirmed purchases included in the Farm-Bike budget sheet, summarising the cost of the components bought.
  
</p>

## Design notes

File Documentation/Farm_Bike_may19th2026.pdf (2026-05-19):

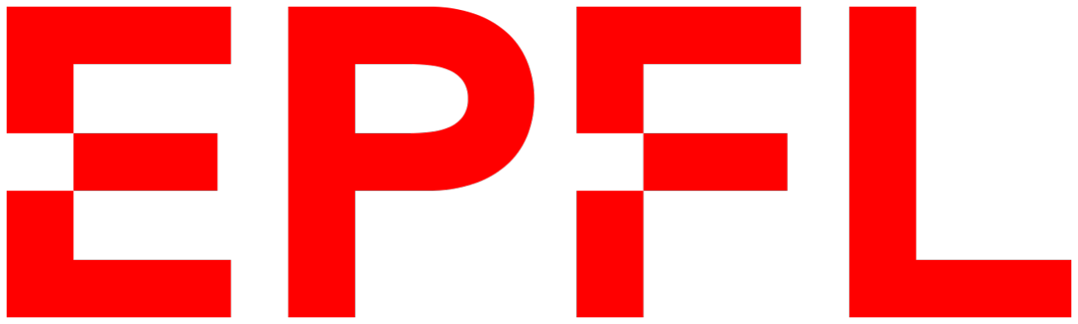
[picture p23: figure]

École Polytechnique Fédérale de Lausanne

# Farm-Bike

Simultaneous Engineering Project

ME-314 Coursework

ME-314 Project Team

May 19, 2026

# Contents

1 Preamble | 1
2 Specification | 2
3 Design | 3
4 Manufacturing | 6
5 Procurement Guide | 10
6 User Guide | 11
7 Testing | 13
A Technical Drawing Annex | 14

i

Farm-Bike | ME-314

ii

# Chapter 1

# Preamble

A simultaneous engineering project at EPFL under the Durabilité unit, which aims to create a modular power source for various farm machinery utilizing human work as the source of power. The development of this machine was the subject of a simultaneous engineering project, course code ME-314, and is the work of a whole semester. The project describes every step from design to machining and testing.

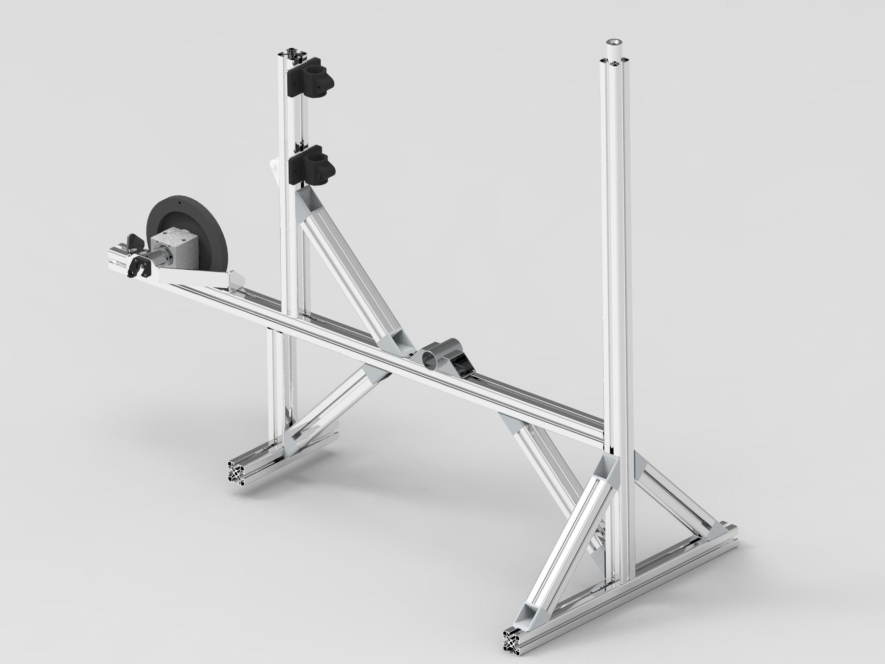
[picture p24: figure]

Figure 1.1: Render of the machine.

The following README contains information that may overlap with other documentation contained in the repository but is not a replacement for those documents.

# Chapter 2

# Specification

### 2.1 Functionality

- Provide a way of converting human power into useful shaft work.
- Have easily adjustable transmission ratio.
- Allow for quick coupling of multiple machines.

### 2.2 Work Environment

- Resist an outdoor work environment subject to a central European climate.
- Resist storage in wet conditions.

### 2.3 Durability

- Be built wherever possible out of standard parts to ensure long term parts availability.
- Machined components to only use conventional machining to provide possibility of field repair.
- Use of quality components to ensure a long life cycle.
- Easy maintenance procedures.

# Chapter 3

# Design

The design of the machine was driven by the specification outlined above and the will to ensure the project can be replicated or further developed in the future. The design choices are driven by the will to create a machine that has a long service life, quality parts and material were chosen over low-cost alternatives.

### 3.1 Frame

The frame is made out of Item modular aluminium extrusions, specifically the profile 8 series. This made the construction of the frame simple and required only off-the-shelf parts. The Item profile 8 can be substituted by any equivalent 40 mm × 40 mm T-slot aluminium extrusion. The choice of aluminium extrusion was made to ensure availability of materials in any geographical region as well as ensure repairability, the ease of manufacture was of course a welcome bonus.

### 3.2 Drivetrain

A transmission based on bicycle components is the optimal off-the-shelf solution to our problem. It offers robustness, ease of maintenance and worldwide availability at a low cost. The following components in the system required no modification from their retail configuration:

- Cassette.
- Derailleur & Shifter.
- Handlebars & Stem.
- Crank set & Bottom Bracket.
- Seat post & Saddle.

The machine is designed to be used as a modular power source for farming implements, many of which are hand-cranked and operate around 60 rpm. The bicycle drivetrain and pulley dimensions were selected so that the operator can adjust the rotational speed without stopping the machine. With the chosen cassette, chainring and pulley diameters, and for an assumed pedalling cadence of 70 rpm, the machine output can vary between approximately 47 rpm and 137 rpm. If another farming implement requires a different speed range, the driven pulley diameter can be changed accordingly.

### 3.3 Gear Ratios and Speed Calculations

The speed calculations are present on the spreadsheet included in the GitHub repository under Documentation/FarmBikeSpeedCalc.xlsx. The assumed rider input is a cadence of 70 rpm and a mechanical power of 250 W. The crank torque is therefore calculated as

Tcrank =

P 60
n 2π

= 34.10 N m.

The high-speed case uses the smallest cassette sprocket, while the low-speed case uses the largest cassette sprocket. The final pulley stage uses a 71 mm drive pulley and a 112 mm driven pulley.

Table 3.1: Gear ratio, speed and torque calculations for the Farm-Bike drivetrain.

Parameter | High-speed setting | Low-speed setting
Chainring teeth | 34 | 34
Cassette sprocket teeth | 11 | 32
Bicycle | drivetrain | ratio | ichain | =

Nchainring/Ncassette

3.09 | 1.06
Hub speed at 70 rpm cadence [rpm] | 216.36 | 74.38
Hub torque for 250 W input [N m] | 11.03 | 32.09
Drive pulley diameter [mm] | 71 | 71
Driven pulley diameter [mm] | 112 | 112
Pulley ratio ipulley = Ddrive/Ddriven | 0.63 | 0.63
Overall speed ratio itot = ichainipulley | 1.96 | 0.67
Machine output speed [rpm] | 137.16 | 47.15
Machine output torque [N m] | 17.40 | 50.63

For the currently selected driven pulley diameter of 112 mm, this range covers the operating speed of the polenta mill and corn sheller used during testing. In the spreadsheet you can also see a centre-to-centre distance of 1000 mm, which gives an estimated belt length of approximately 2288 mm for the 71 mm and 112 mm pulley pair.
The subsequent paragraphs describe the design of each of the machine-specific parts. The parts were designed to conform with bicycle industry standards such that commissioning and maintenance could be carried out by anyone familiar with common bicycles.

### 3.3.1 Bottom Bracket Shell

The bottom bracket shell attaches the standard BSA bicycle bottom bracket to the frame. The part is a weldment of a round bottom bracket shell recovered from a donor frame and a 40 mm × 30 mm rectangular steel tube. The part requires far less material resources than an equivalent machined from a billet and does not require specialty tooling to cut the BSA thread.

### 3.3.2 Hub

The hub forms a central part of the transmission of the machine, it mounts the cassette and the pulley thus transmitting all of the power generated. A flywheel is also mounted on the axle to smooth out the power delivery.

### 3.3.3 Pillow Block

This part houses the main bearings and attaches to the frame. It is a crucial part that maintains the alignment between the two bearings and ensures their long life and smooth operation, for this reason it is machined out of a 6061 aluminium billet. Due to unavailability of appropriate stock the pillow block has been split into two pieces and pinned together. It features clearance holes for two M8 mounting bolts, a central bore for the axle to pass through and two counterbores for the 6005-2Z bearings. These deep groove ball bearings have been selected to ensure a long life span as well being easy to source. Low profile ball bearings often found in bicycles have specifically been discarded as their lower profile makes them more prone to premature failure. A recess has been added at the mounting between the pillow block and the aluminium profile to prevent twisting during usage.

### 3.3.4 Axle

The large bearings allow us to use an aluminium axle without risking the keyway becoming fragile. The axle features 25 mm bearing seats and a key way to transmit torque to the flywheel and pulley. In order to mount the cassette onto the axle while avoiding complex machining operations a donor freehub body was bonded onto the axle. The axle was of course designed around the specific freehub body available thus the design would need to be modified in accordance with available parts.

### 3.3.5 Derailleur Hanger

To emulate the derailleur mounting of a conventional bicycle without having to cut a fine pitch thread a derailleur hanger from a donor frame was utilized. In order to correctly position it with respect to the axle and cassette a mount was designed out of 3 mm 5005 aluminium sheet. The mount exploits the advantages of bent sheet metal to achieve a robust yet lightweight solution.

# Chapter 4

# Manufacturing

This section outlines the manufacturing processes of each of the parts and provides photos of the components. It assumes the reader is comfortable with conventional machining processes and general fabrication and thus omits the details of most trivial operations. Some parts in the assembly are overlooked in this section as their manufacturing features no operations of interest.

### 4.1 Bottom Bracket Shell

This is the only weldment on the machine, consisting of two parts with thin sections. The donor frame was chosen for its steel construction and BSA threaded bottom bracket. The shell was cut out and turned down to a constant diameter. During the turning operations a close fitting aluminium plug was used on the inside of the threads to provide tailstock support. The hole for the shell in the rectangular tubing was roughed out with a hole saw on a mill and fitted by hand with a file. The two parts were subsequently TIG welded and the thread was chased. TIG welding was used because of the thin material and in order to preserve as much of the BSA thread inside the shell.

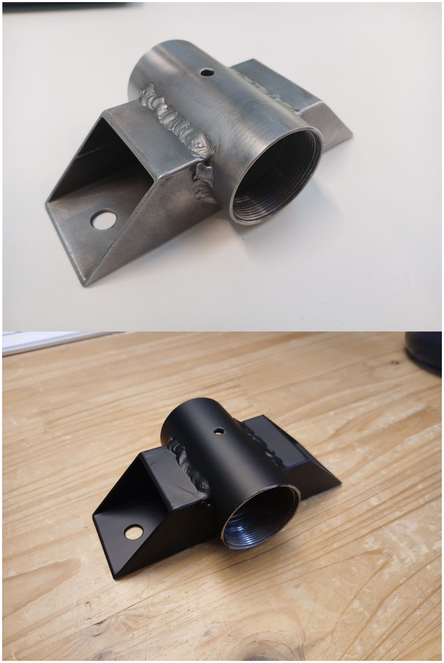
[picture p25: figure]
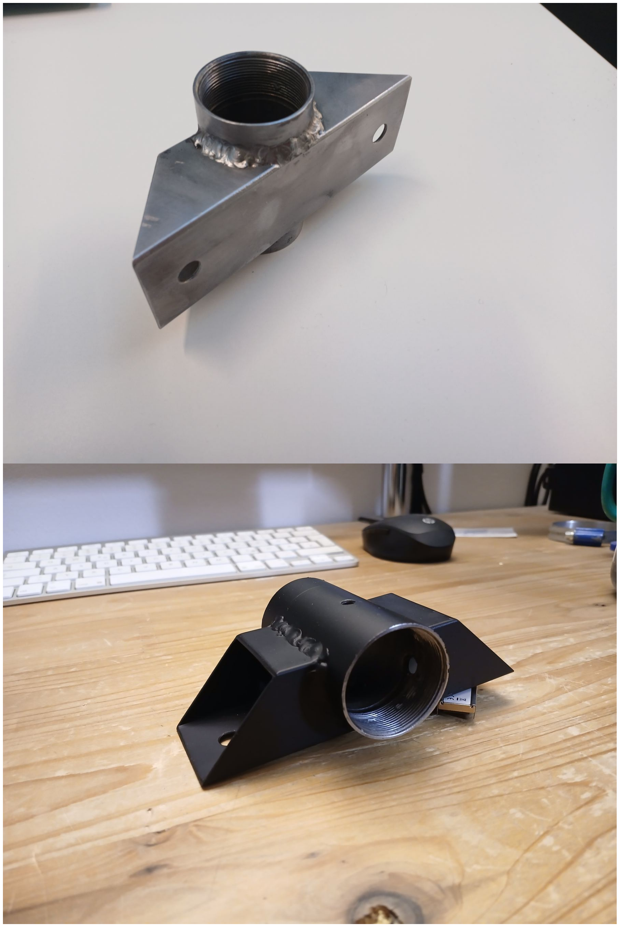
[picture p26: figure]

Figure 4.1: Bottom bracket shell manufacturing steps.

After welding, the oxides were removed and the part was finished with automotive anti-rust

primer.

### 4.2 Axle

The machining operations did not deviate from standard practice. Loctite 603 retaining compound was used to chemically bond the freehub body to the axle. Chemical bonding was chosen to remove the need for pressing in the axle thus eliminating the risk of fracture on the hardened freehub body.

### 4.3 Pillow Block

Due to limitations in the available stock material the pillow block was machined from two separate pieces of stock.
The operations were carried out in the following order:
- Squaring the stock to size.
- Drilling and reaming of the 4 mm pin bores.
- Centre drilling of the main bore.
- Two parts are pressed together.
- Milling locating slot.
- Drilling of two M8 clearance holes.
- Boring half of the through bore in a lathe with centre drill hole as reference.
- Boring of bearing seat.
- Part flipped and boring operations repeated.
- Deburring and chamfering.

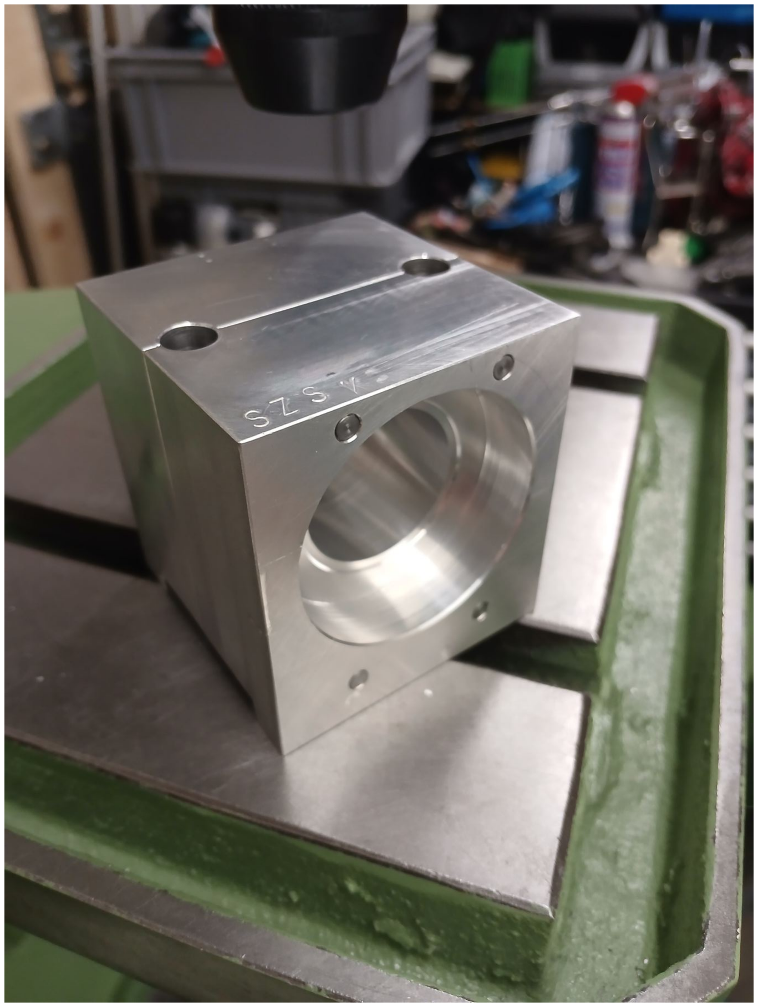
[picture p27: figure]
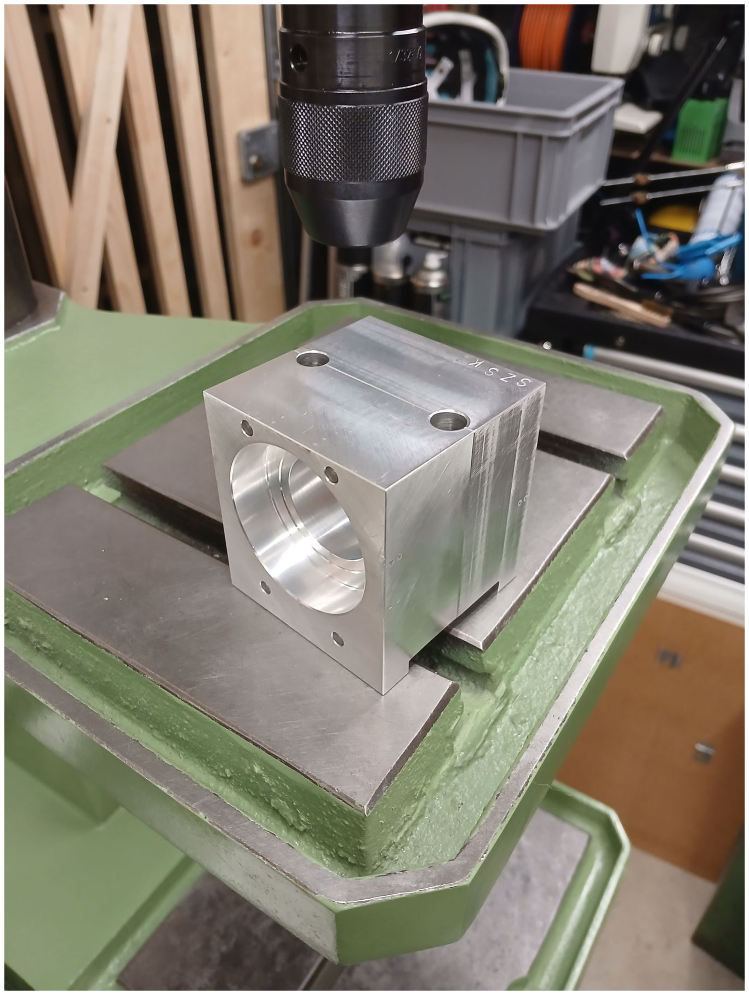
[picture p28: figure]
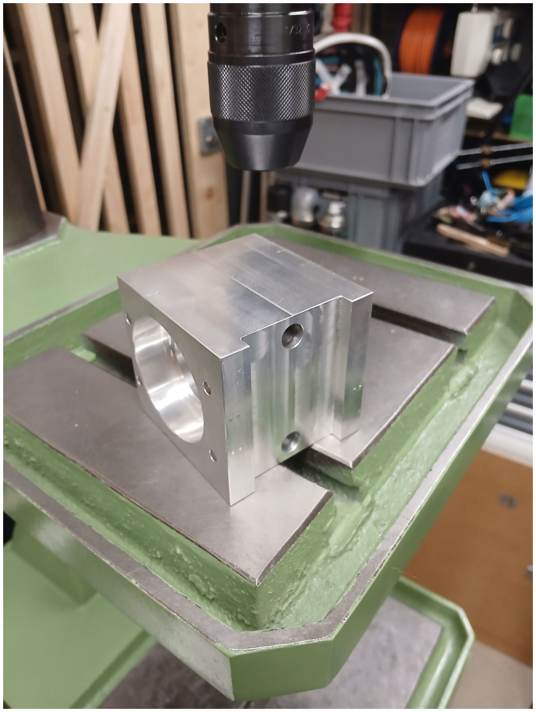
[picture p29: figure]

Figure 4.2: Pillow block manufacturing steps.

Following machining, deburring and finishing was carried out and the bearings were fitted.

### 4.4 Fly Wheel

In order to avoid procuring costly stock material the fly wheel is cut out of 5 mm S235 structural steel and the pieces are pinned together. The use of a fibre laser allows for significant time saving but all of the parts can be machined using conventional processes. The parts were pressed together with an arbor press and a coat of anti-rust primer protects against corrosion.

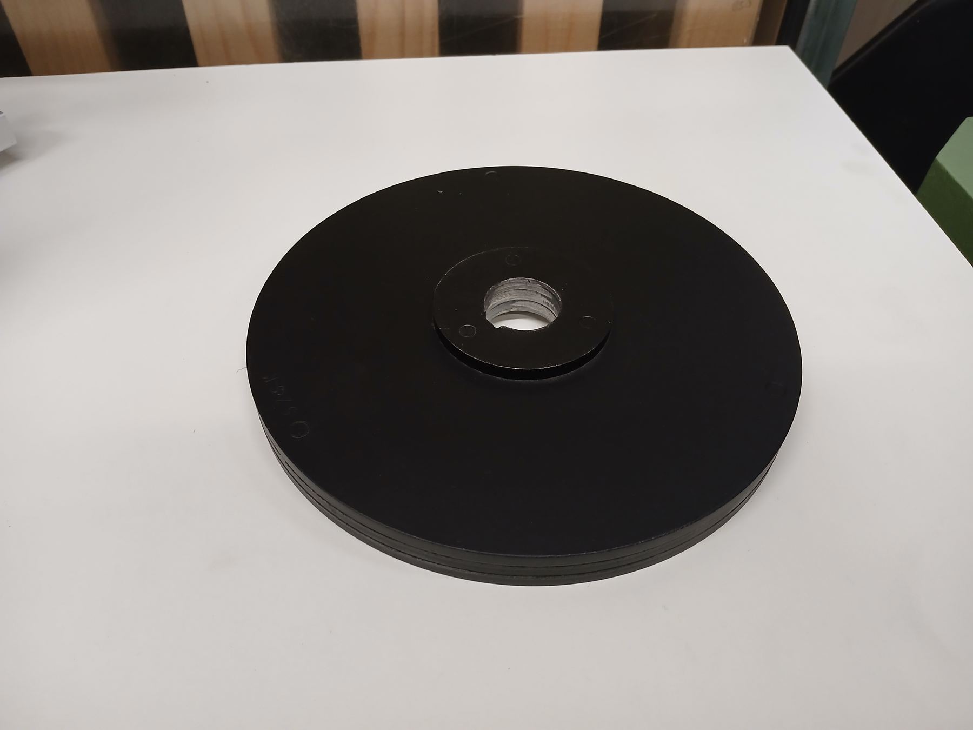
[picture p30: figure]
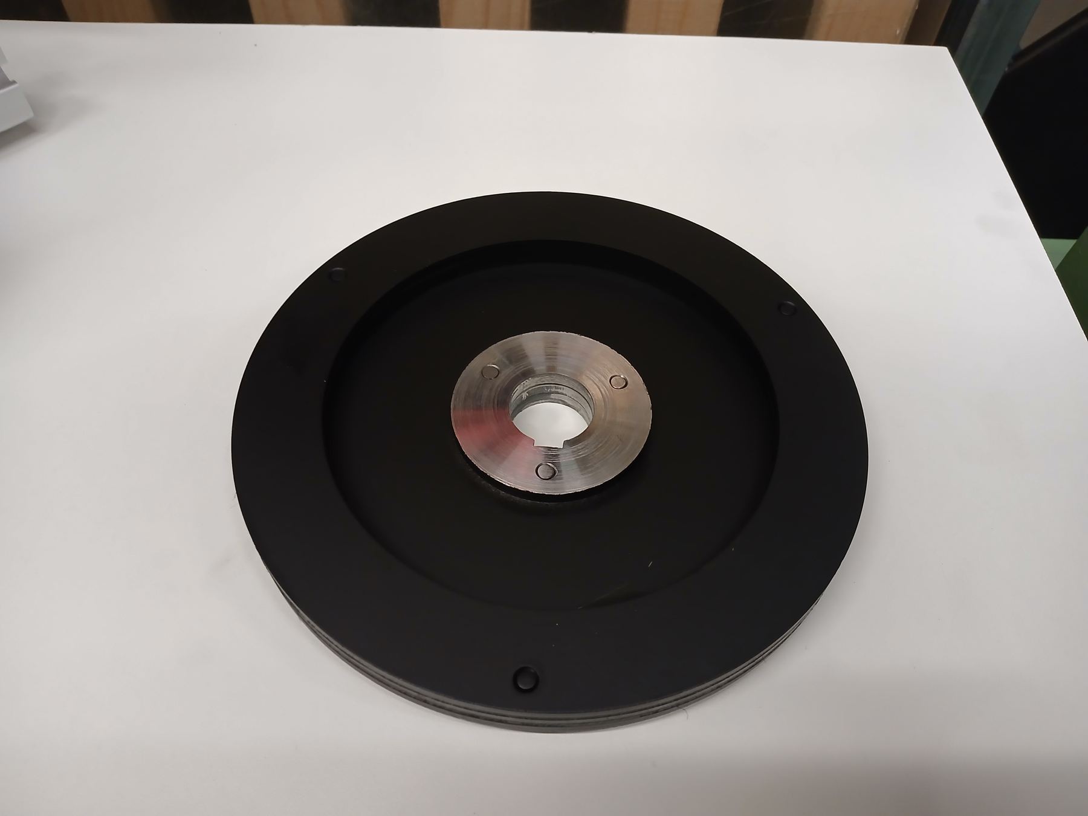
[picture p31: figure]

Figure 4.3: Fly wheel manufacturing and assembly.

### 4.5 Hub

Precautions taken during assembly of the hub:

- Parts cleaned and lubricated.
- Light preload applied to the bearings.
- Taper lock pulley and bushing torqued to manufacturer specification.

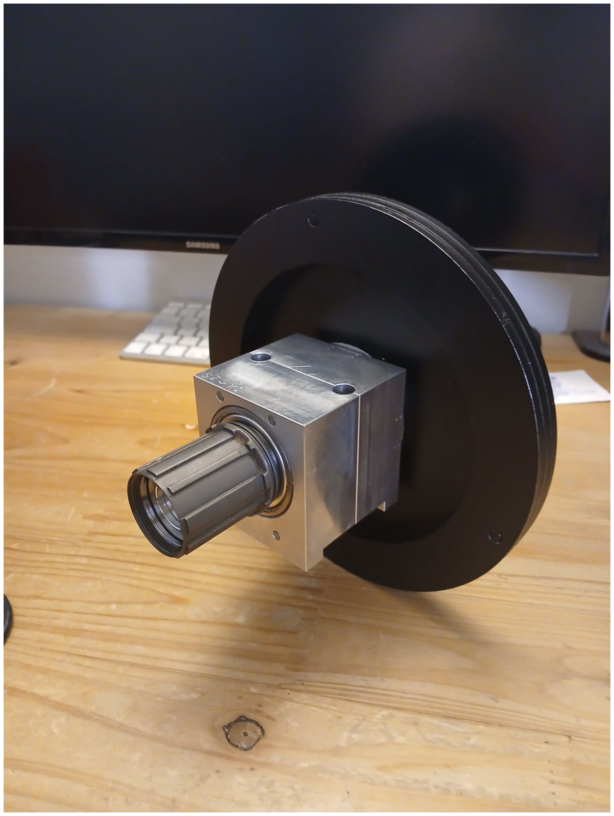
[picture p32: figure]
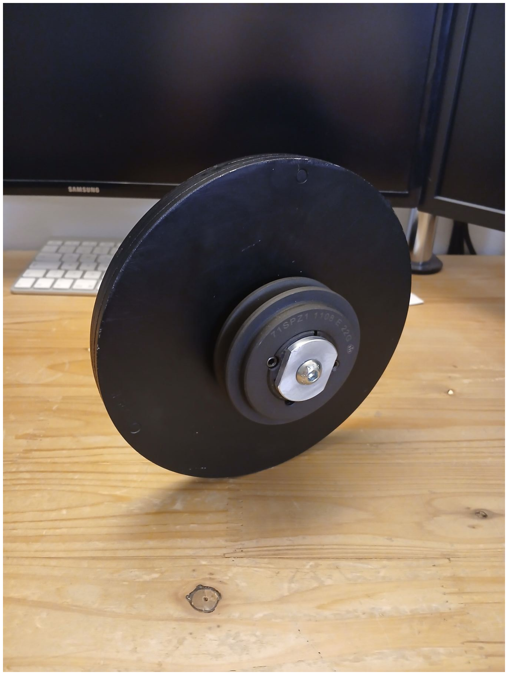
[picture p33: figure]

Figure 4.4: Hub assembly.

### 4.6 Derailleur Mount

Just like the fly wheel the derailleur mount was cut with the use of a fibre laser. Due to its non-trivial geometry the sheet metal part was bent in a bench vice with the help of parallel jaw pliers. The existing derailleur hanger was hand fitted during the finishing process. As most of the part geometries are non-mating surfaces the part could be replicated with hand tools. The geometry can be modified to suit the manufacturing methods available.

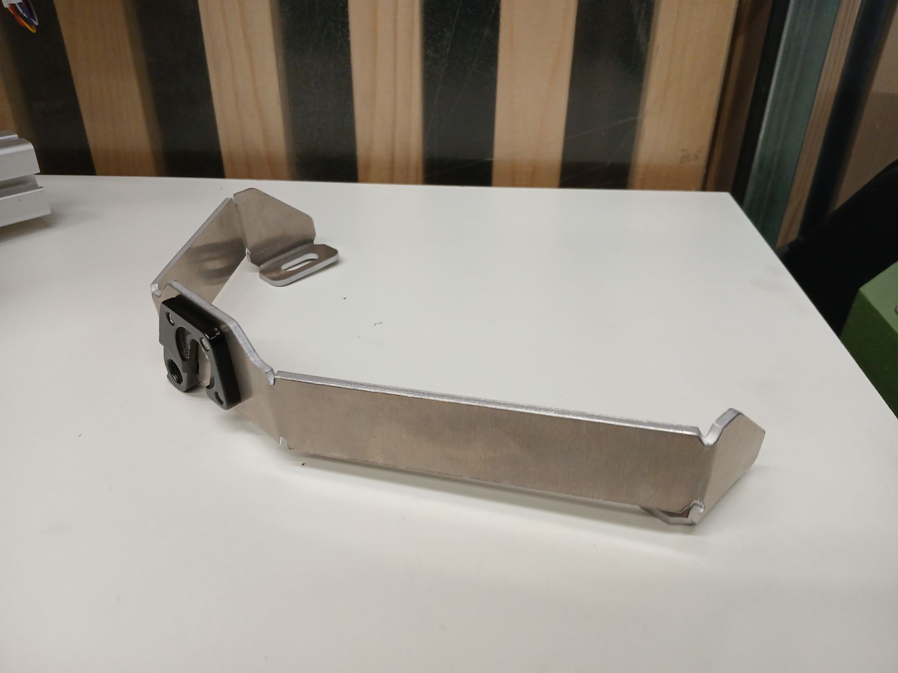
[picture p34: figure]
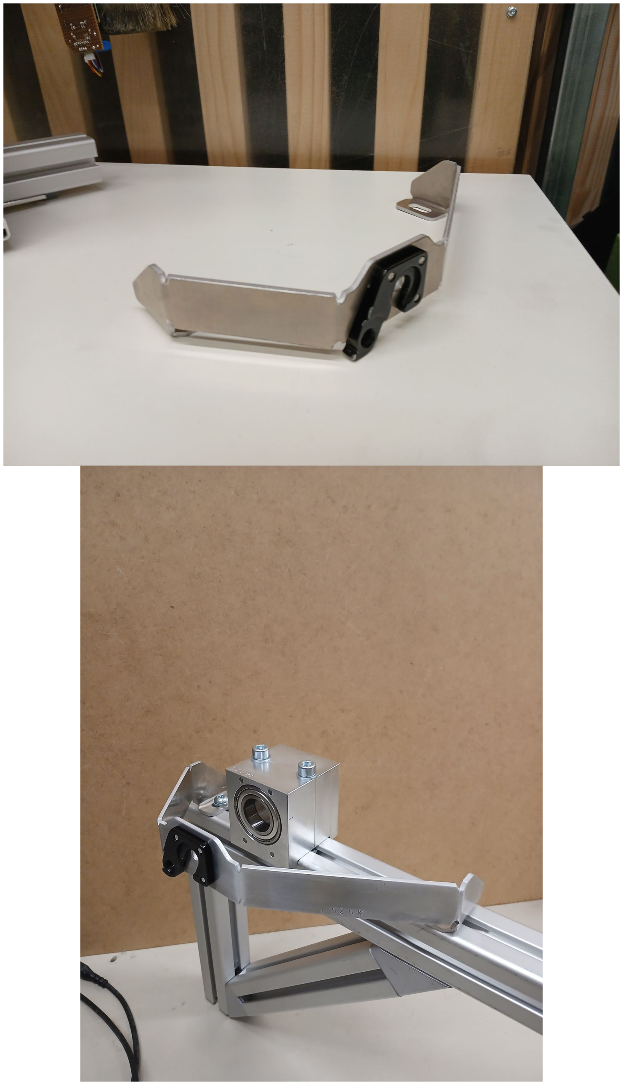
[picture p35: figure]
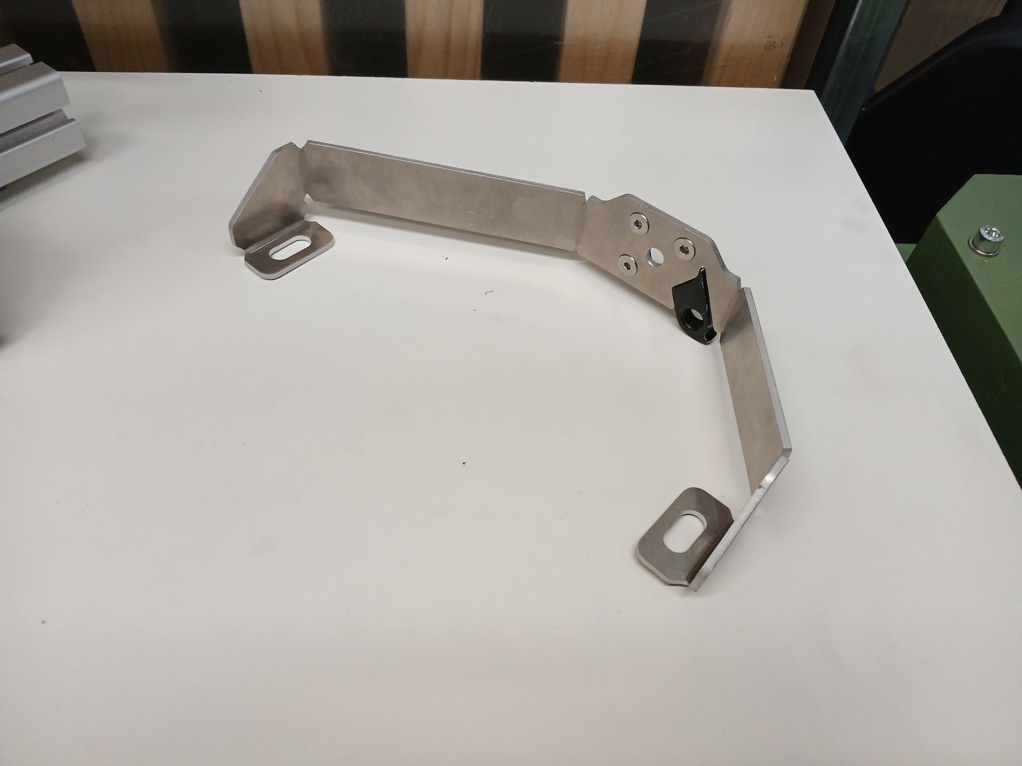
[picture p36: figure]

Figure 4.5: Derailleur mount manufacturing and fitting.

# Chapter 5

# Procurement Guide

Normalized industrial parts for this project can be commonly bought new from well established suppliers. The parts for the prototype were sourced from Norelem, but equivalent parts can be sourced from:

- Misumi.
- RS Components.
- McMaster-Carr.
- JLCMC.

To reduce the ecological impact of the prototype second hand or recovered components were utilized in areas that would not impact the longevity, safety or operation of the machine.
Item aluminium profiles and relevant hardware were recovered from decommissioned machinery. Equivalents can be sourced from the suppliers above or Item24 directly. Wherever possible material off-cuts or scrapped parts were used as stock material.
Bicycle components for the prototype were second hand and sourced from Point Vélo located on the EPFL campus.

# Chapter 6

# User Guide

### 6.1 Use Instructions

Before operating the machine, ensure that it is placed on a stable and level surface. The frame should not rock or move under load, and all fasteners securing the aluminium profiles, pillow block, bottom bracket shell, seat post and handlebar assembly should be checked for tightness. The pulley, flywheel and cassette should be visually inspected to ensure that they are correctly seated and that no foreign object is interfering with the drivetrain.
The user should adjust the saddle height and handlebar position to obtain a comfortable pedalling position. As with a conventional bicycle, the saddle height should allow the leg to remain slightly bent at the bottom of the pedal stroke. The drivetrain can then be shifted using the standard bicycle shifter in order to select the desired transmission ratio. The rear derailleur can be shifted using the standard handlebar shifter, while the front chainring selection has to be carried out manually. The user should therefore stop pedalling, wait for the drivetrain to come to rest, and move the chain by hand only when the machine is fully stationary. This should be done by getting off the bike, adjusting the chain to the desired chainring setting and gently cranking the pedals by hand such that the chain jumps into its desired place. The user can afterwards get back onto the bike and pedal normally. Lower gears should be used when starting the machine or when driving a high-load implement, while higher gears can be used once the system is already rotating smoothly or when a higher output speed is required.
To start the machine, the user should begin pedalling progressively and avoid sudden impacts on the pedals. The flywheel will gradually store kinetic energy and smooth out the power delivery. Once the machine is rotating steadily, the selected gear ratio can be adjusted depending on the required output speed and the resistance of the coupled machine. Gear changes should preferably be carried out while pedalling with moderate force, in the same way as on a standard bicycle, in order to avoid excessive stress on the chain and derailleur.
Before coupling the Farm-Bike to an external machine, the user must ensure that the driven machine is compatible with the output speed, torque and rotation direction of the system. The coupling should be securely mounted and aligned with the pulley or output shaft to avoid vi-brations, belt slipping or premature wear. During operation, hands, clothing and loose objects must be kept away from the chain, cassette, pulley, flywheel and any rotating element.
To stop the machine, the user should simply reduce pedalling effort progressively and allow the drivetrain and flywheel to slow down naturally. The user should not attempt to stop the flywheel, pulley or chain by hand. After use, the machine should be inspected for loose fasteners, abnormal noise, chain misalignment or signs of wear. If the machine has been used outdoors or stored in humid conditions, exposed steel parts should be dried and checked for corrosion.

### 6.2 Maintenance Guide

Time intervals for preventative maintenance are guidelines only. Maintenance intervals should be adjusted according to the conditions of use and storage.

- Before each use: inspect fasteners and drivetrain.
- Every 7–10 hours: clean and lubricate the chain.
- Every 30–50 hours: degrease and lubricate the chain.
- Every 100 hours: inspect the drivetrain for wear.
- Every 150 hours: disassemble and inspect the hub and crankset.

Parts deemed inoperable during inspection are to be replaced. For a more detailed expla-nation of fitting, adjusting and maintaining bicycle-specific components, refer to the General Operations Manual, DM-GN0001, published by Shimano.

### 6.3 Troubleshooting Guide

Table 6.1: Common operating issues and likely causes.

Issue | Likely cause | Corrective action
Unusual noise | Loose fastener | Verify and tighten fasteners.
Chain skips under power | Worn drivetrain components | Replace the chain. If the is-
| | sue persists, replace the cas-
| | sette and chainrings.
Chain jumps between gears Shifting not adjusted | Adjust the shift cable.
Chain falls off the top or bottom of the cassette | Derailleur limits out of adjust-
| ment | Adjust the derailleur limits.
Excessive friction in drive- train under no load | Debris stuck or tangled in the
| drivetrain | Inspect the drivetrain and re-
| | move debris.

# Chapter 7

# Testing

### 7.1 Initial Testing: 14/05/2026 (Week 12)

The first functional test was carried out directly at the Bassenges farm. The Farm-Bike prototype was brought to the farm and connected to two existing machines: the polenta grinder and the corn sheller. Pulleys were installed on both machines, after which the bike was coupled to the system and tested. The first test was successful, as the Farm-Bike was able to drive the machines through the belt transmission. The whole Bassenges team was present during the test. However, once the system was operating, an important ergonomic issue was identified by Timothée, the farmer responsible for following the project at the Bassenges farm. In the initial configuration, the bike was not facing the machines. This meant that a single operator could not comfortably pedal the bike and load the machines at the same time. This feedback highlighted an important practical limitation of the first assembly.
After considering the problem, we realized that the modular aluminium profile frame made it possible to rearrange the bike without manufacturing new parts. Several components were repositioned so that the pulley attachment faced the opposite direction and was located at the front of the bike. This reassembly took approximately an hour and a half, but it allowed the Farm-Bike to be adapted directly to the farmer’s request. Due to the lack of equipment at the farm, we were not able to reduce the length of the chain, which is planned for the following week. Initial testing confirmed the value of using modular aluminium profiles for the frame. The ability to modify the geometry of the machine on site was a major advantage during the testing phase. If the frame had been fully welded or made as a fixed steel structure, this last-minute correction would not have been possible without significant rework.
The following images show the Farm-Bike before and after the reassembly:

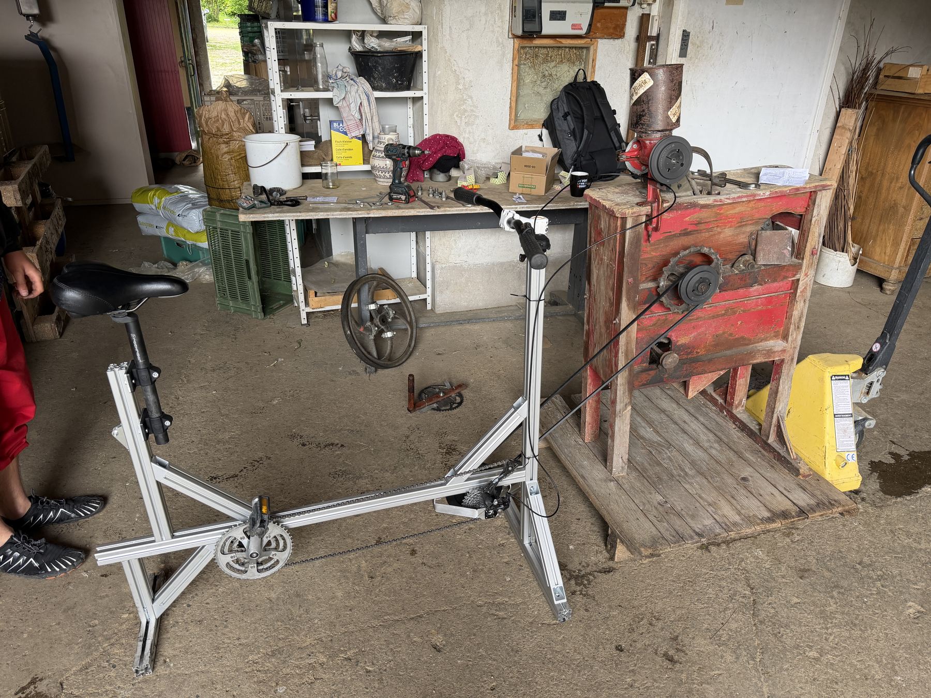
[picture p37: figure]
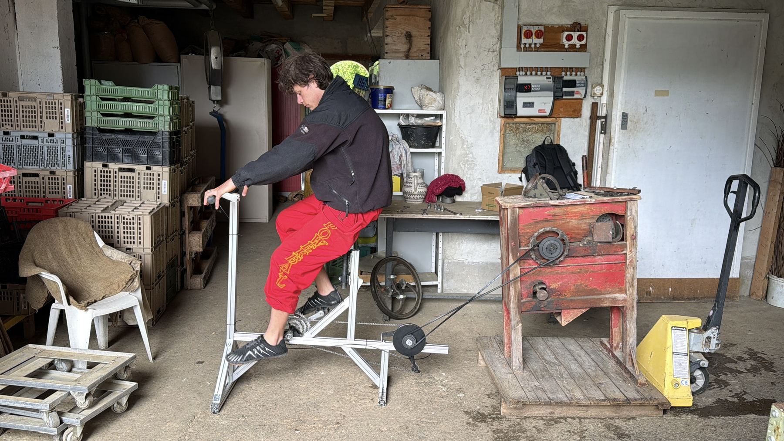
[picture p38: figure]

Initial configuration | Modified configuration

Figure 7.1: Farm-Bike configuration before and after the first testing session at Bassenges farm.

# Appendix A

# Technical Drawing Annex

This annex gathers the PDF technical drawings stored in the Drafts section of the GitHub repository.

### A.1 BBMount

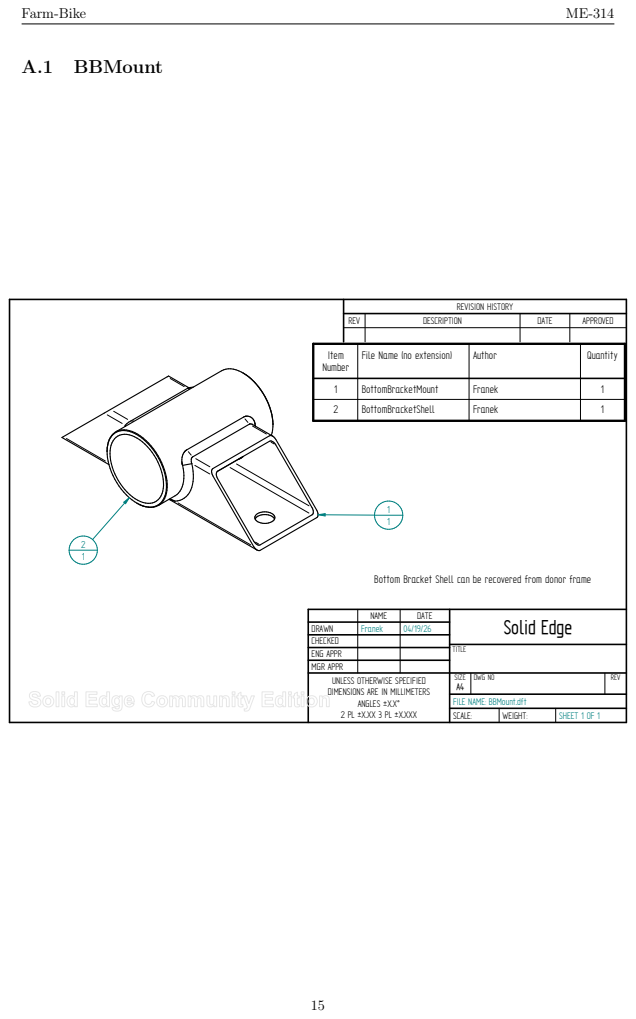
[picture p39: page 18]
SCALE:; WEIGHT:; SHEET 1 OF 1

REVISION HISTORY

REV | DESCRIPTION | DATE | APPROVED

Item Number | File Name (no extension) | Author | Quantity

1 | BottomBracketMount | Franek | 1
2 | BottomBracketShell | Franek | 1

Bottom Bracket Shell can be recovered from donor frame

NAME | DATE | Solid Edge

DRAWN | Franek | 04/19/26
CHECKED
ENG APPR | | | TITLE
MGR APPR
UNLESS OTHERWISE SPECIFIED DIMENSIONS ARE IN MILLIMETERS ANGLES ±X.X° 2 PL ±X.XX 3 PL ±X.XXX | SIZE A4 | DWG NO | REV

FILE NAME: BBMount.dft

### A.2 Bottom Bracket Mount

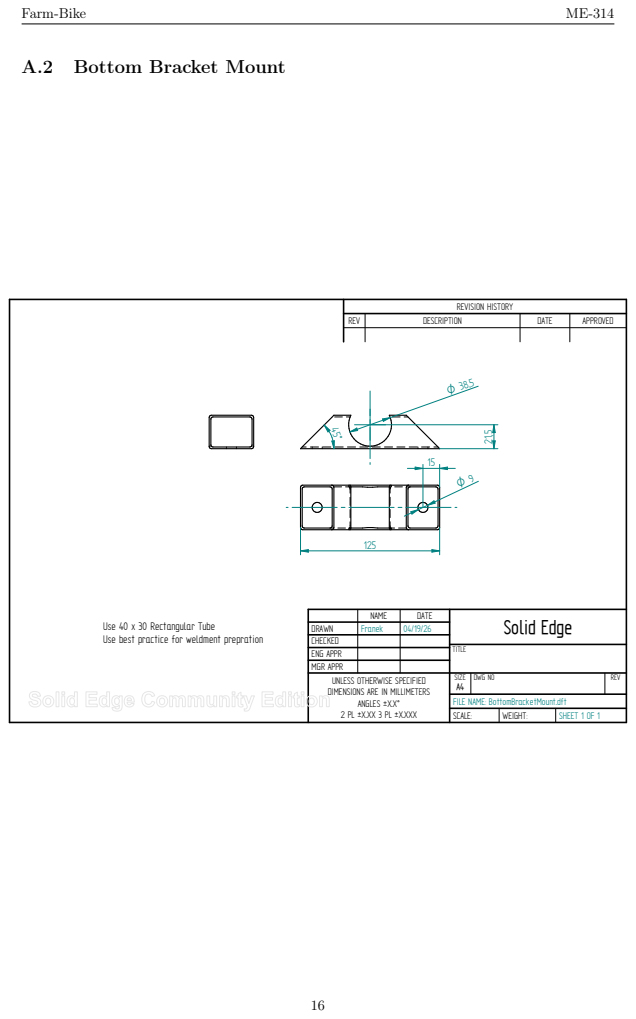
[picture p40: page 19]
SCALE:; WEIGHT:; SHEET 1 OF 1

REVISION HISTORY

REV | DESCRIPTION | DATE | APPROVED

NAME | DATE | Solid Edge

Use 40 x 30 Rectangular Tube
Use best practice for weldment prepration

DRAWN | Franek | 04/19/26
CHECKED
ENG APPR | | | TITLE
MGR APPR
UNLESS OTHERWISE SPECIFIED DIMENSIONS ARE IN MILLIMETERS ANGLES ±X.X° 2 PL ±X.XX 3 PL ±X.XXX | SIZE A4 | DWG NO | REV

FILE NAME: BottomBracketMount.dft

### A.3 Drive Axle

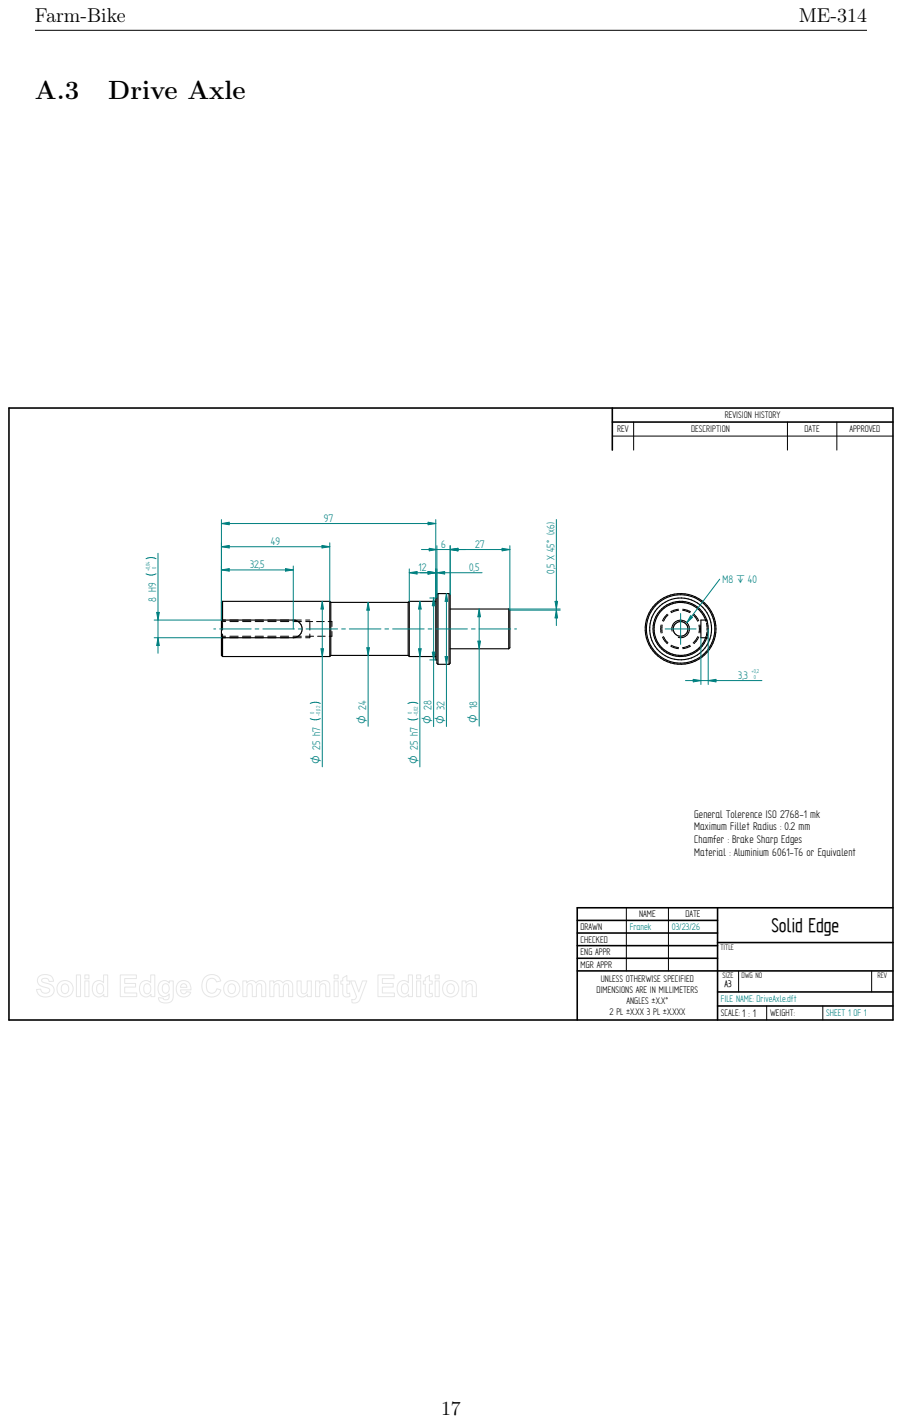
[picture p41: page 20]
SCALE:; WEIGHT:; SHEET 1 OF 1

REVISION HISTORY

REV | DESCRIPTION | DATE | APPROVED

General Tolerence ISO 2768-1 mk
Maximum Fillet Radius : 0.2 mm
Chamfer : Brake Sharp Edges
Material : Aluminium 6061-T6 or Equivalent

DRAWN | Franek | 03/23/26
CHECKED
ENG APPR | | | TITLE
MGR APPR
UNLESS OTHERWISE SPECIFIED DIMENSIONS ARE IN MILLIMETERS ANGLES ±X.X° 2 PL ±X.XX 3 PL ±X.XXX | SIZE A3 | DWG NO | REV

NAME | DATE | Solid Edge

FILE NAME: DriveAxle.dft

### A.4 Farm Bike Assembly

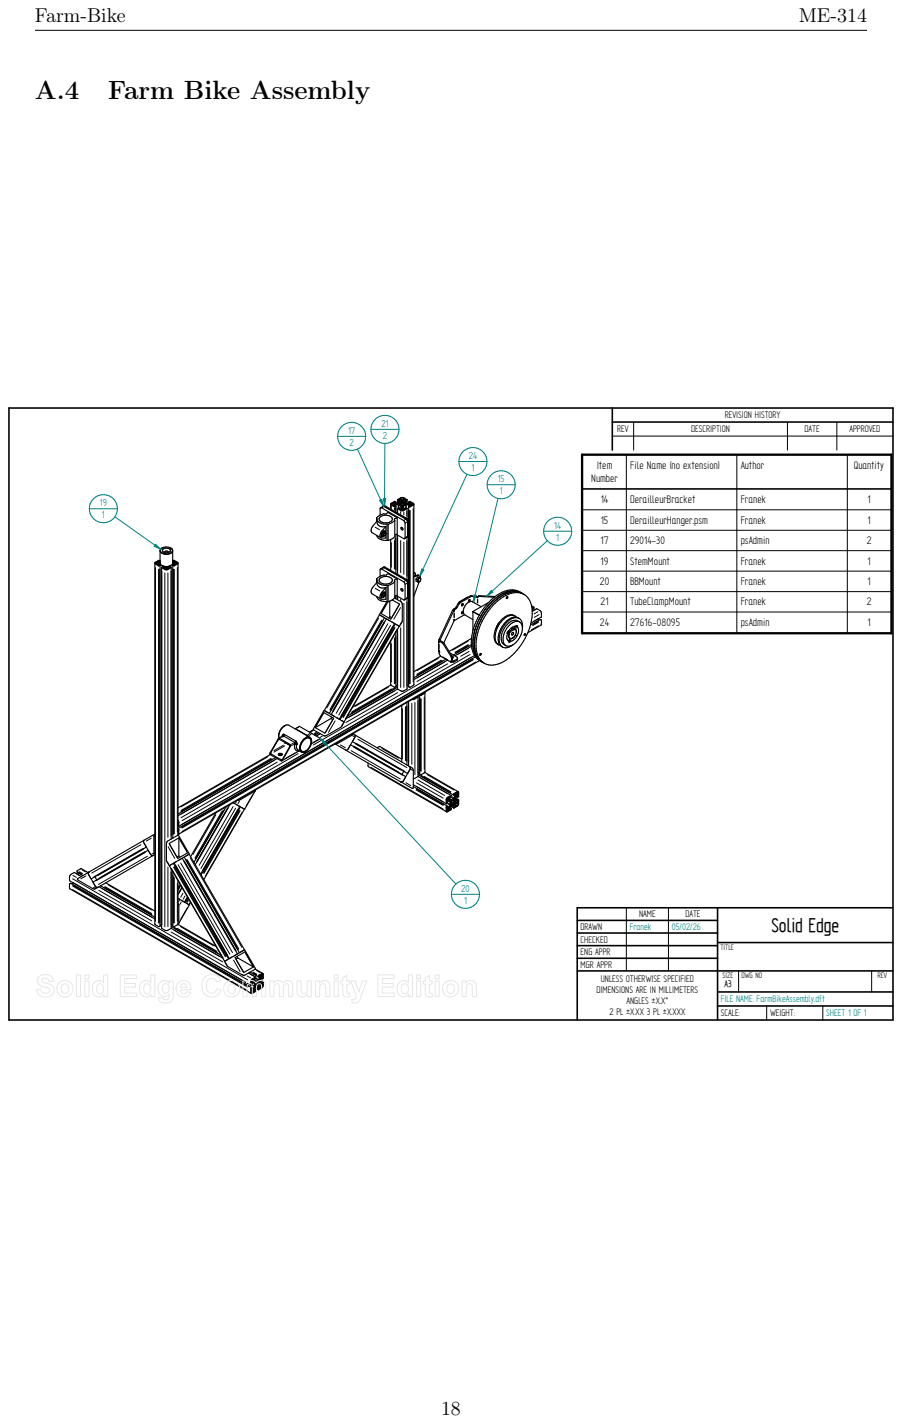
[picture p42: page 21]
SCALE:; WEIGHT:; SHEET 1 OF 1

REVISION HISTORY

REV | DESCRIPTION | DATE | APPROVED

Item Number | File Name (no extension) | Author | Quantity

14 | DerailleurBracket | Franek | 1
15 | DerailleurHanger.psm | Franek | 1
17 | 29014-30 | psAdmin | 2
19 | StemMount | Franek | 1
20 | BBMount | Franek | 1
21 | TubeClampMount | Franek | 2
24 | 27616-08095 | psAdmin | 1

DRAWN | Franek | 05/02/26
CHECKED
ENG APPR | | | TITLE
MGR APPR
UNLESS OTHERWISE SPECIFIED DIMENSIONS ARE IN MILLIMETERS ANGLES ±X.X° 2 PL ±X.XX 3 PL ±X.XXX | SIZE A3 | DWG NO | REV

NAME | DATE | Solid Edge

FILE NAME: FarmBikeAssembly.dft

### A.5 Frame Assembly

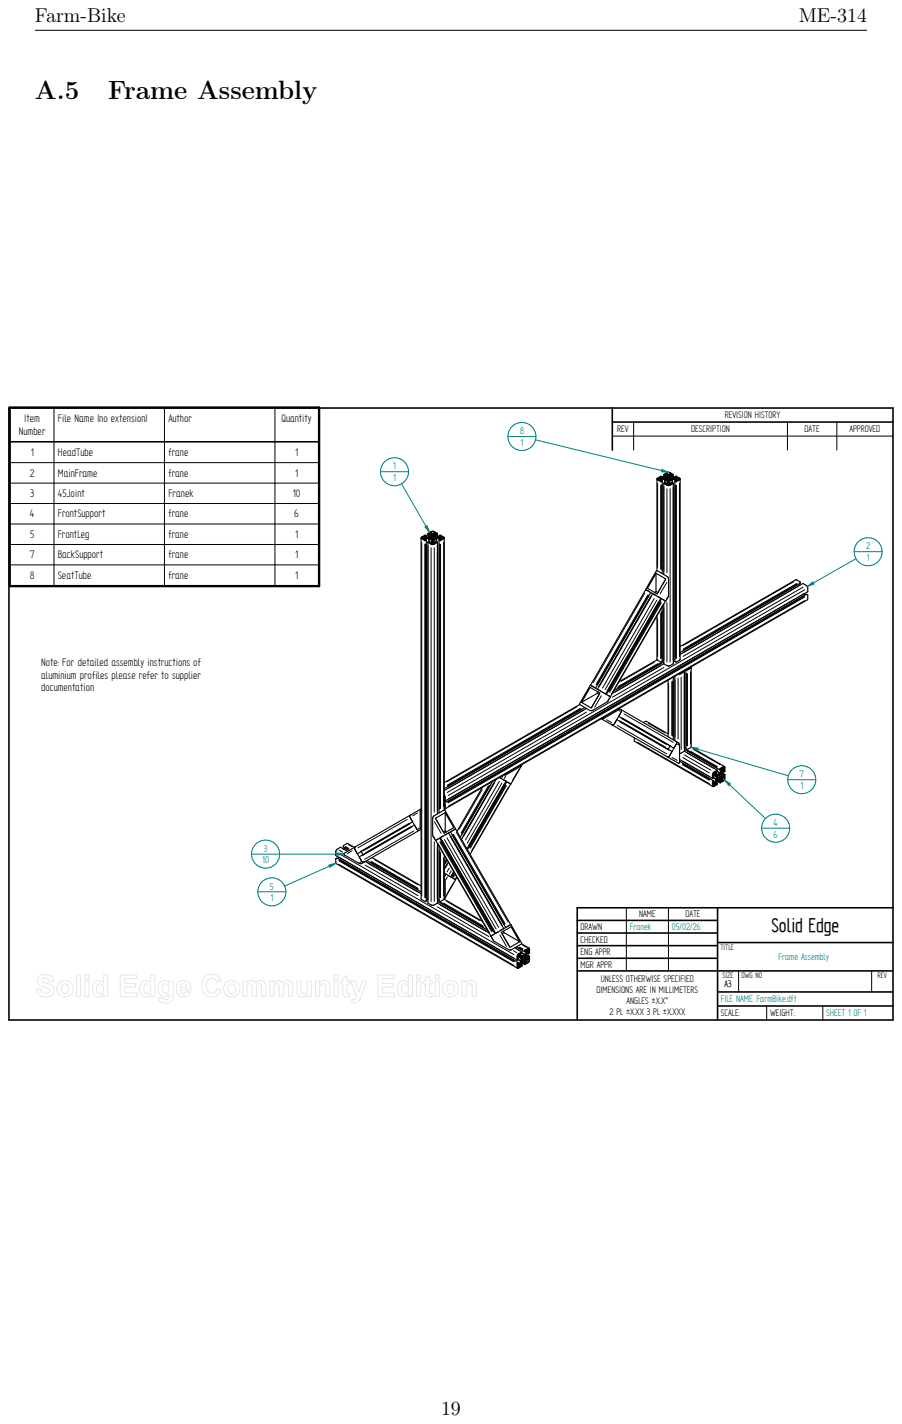
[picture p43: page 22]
SCALE:; WEIGHT:; SHEET 1 OF 1

Item Number | File Name (no extension) | Author | Quantity | REVISION HISTORY

REV | DESCRIPTION | DATE | APPROVED

1 | HeadTube | frane | 1
2 | MainFrame | frane | 1
3 | 45Joint | Franek | 10
4 | FrontSupport | frane | 6
5 | FrontLeg | frane | 1
7 | BackSupport | frane | 1
8 | SeatTube | frane | 1

Note: For detailed assembly instructions of
aluminium profiles please refer to supplier
documentation

DRAWN | Franek | 05/02/26
CHECKED
ENG APPR | | | TITLE Frame Assembly
MGR APPR
UNLESS OTHERWISE SPECIFIED DIMENSIONS ARE IN MILLIMETERS ANGLES ±X.X° 2 PL ±X.XX 3 PL ±X.XXX | SIZE A3 | DWG NO | REV

NAME | DATE | Solid Edge

FILE NAME: FarmBike.dft

### A.6 Hub Exploded

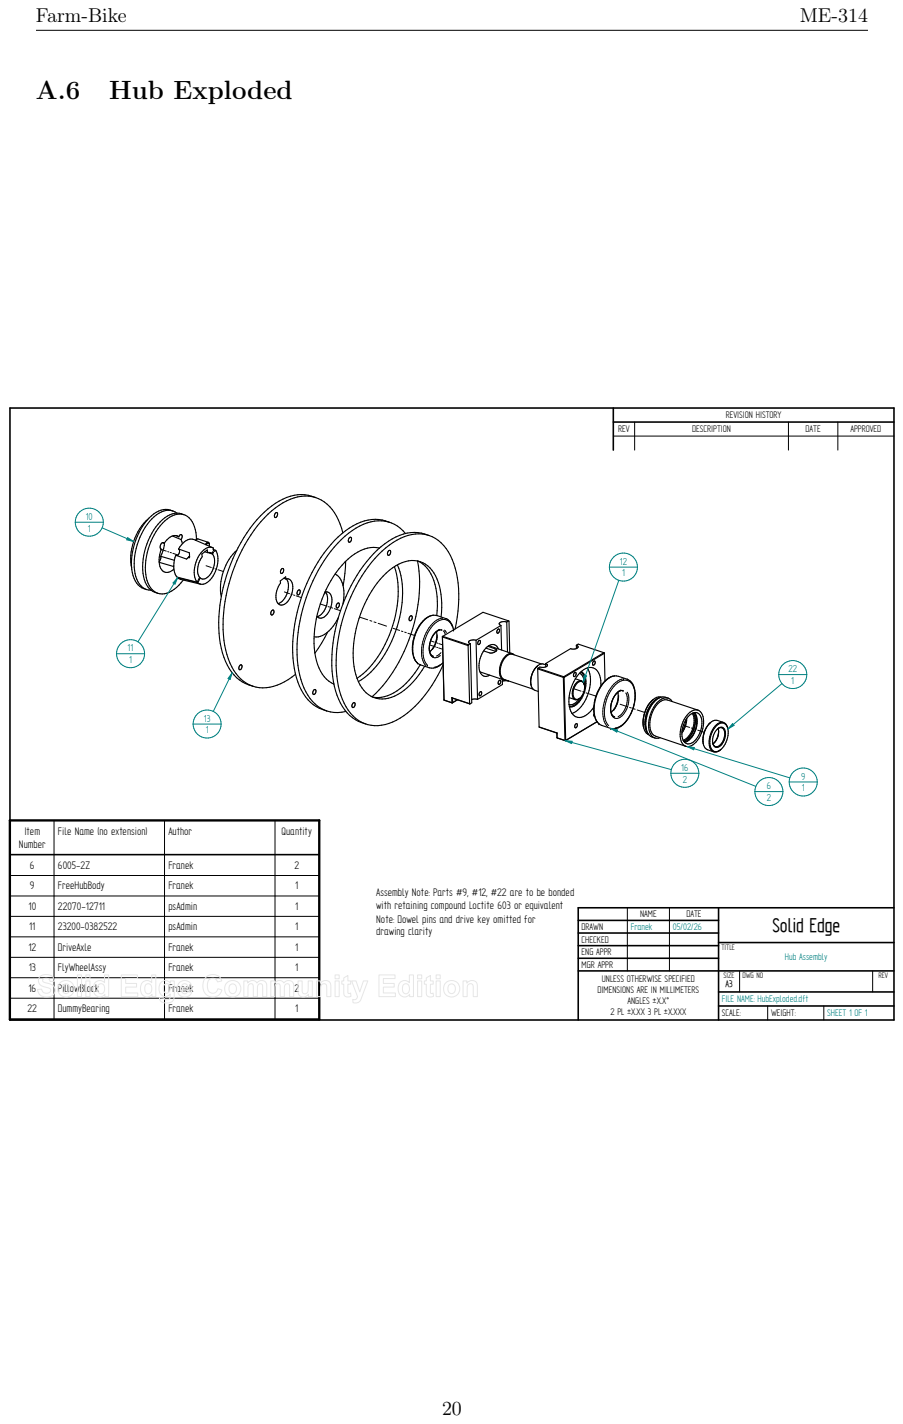
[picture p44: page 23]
DRAWN CHECKED ENG APPR MGR APPR; NAME Franek; DATE; Solid Edge; TITLE; Hub Assembly; psAdmin; DriveAxle; Franek; FlyWheelAssy

10 1 11 1 13 1 | REVISION HISTORY

REV | DESCRIPTION | DATE | APPROVED

Item Number | File Name (no extension) | Author | Quantity

6 | 6005-2Z | Franek | 2
9 | FreeHubBody | Franek | 1
10 | 22070-12711 | psAdmin | 1

Assembly Note: Parts #9, #12, #22 are to be bonded
with retaining compound Loctite 603 or equivalent
Note: Dowel pins and drive key omitted for
drawing clarity

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

16 | PillowBlock | Franek | 2
22 | DummyBearing | Franek | 1

FILE NAME: HubExploded.dft

SCALE: | WEIGHT: | SHEET 1 OF 1

### A.7 Pillow Block

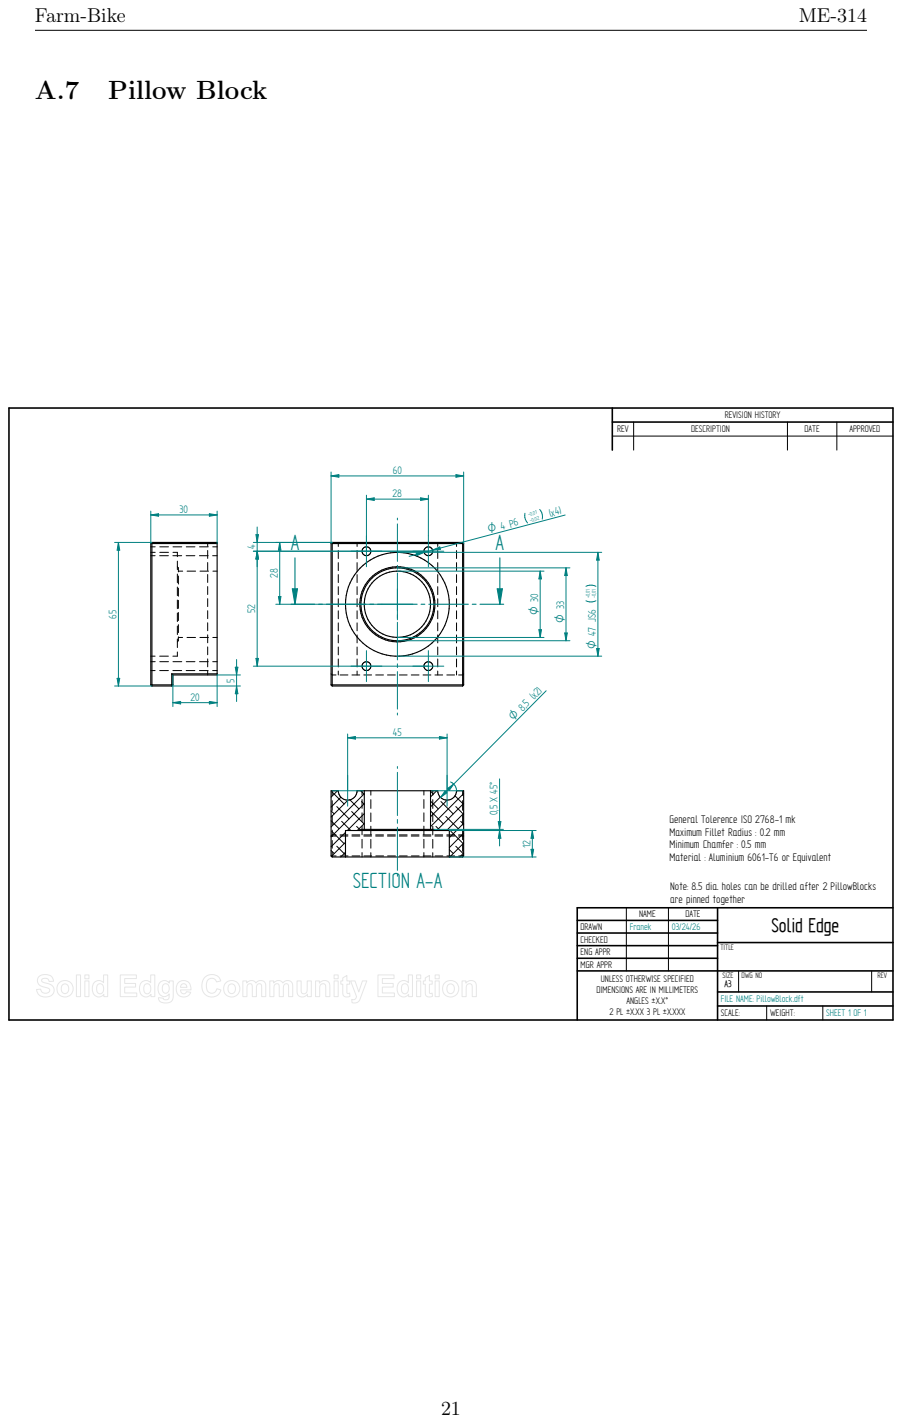
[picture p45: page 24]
SCALE:; WEIGHT:; SHEET 1 OF 1; SECTION A-A

REVISION HISTORY

REV | DESCRIPTION | DATE | APPROVED

General Tolerence ISO 2768-1 mk
Maximum Fillet Radius : 0.2 mm
Minimum Chamfer : 0.5 mm
Material : Aluminium 6061-T6 or Equivalent

Note: 8.5 dia. holes can be drilled after 2 PillowBlocks
are pinned together

DRAWN | Franek | 03/24/26
CHECKED
ENG APPR | | | TITLE
MGR APPR
UNLESS OTHERWISE SPECIFIED DIMENSIONS ARE IN MILLIMETERS ANGLES ±X.X° 2 PL ±X.XX 3 PL ±X.XXX | SIZE A3 | DWG NO | REV

NAME | DATE | Solid Edge

FILE NAME: PillowBlock.dft

### A.8 Stem Mount

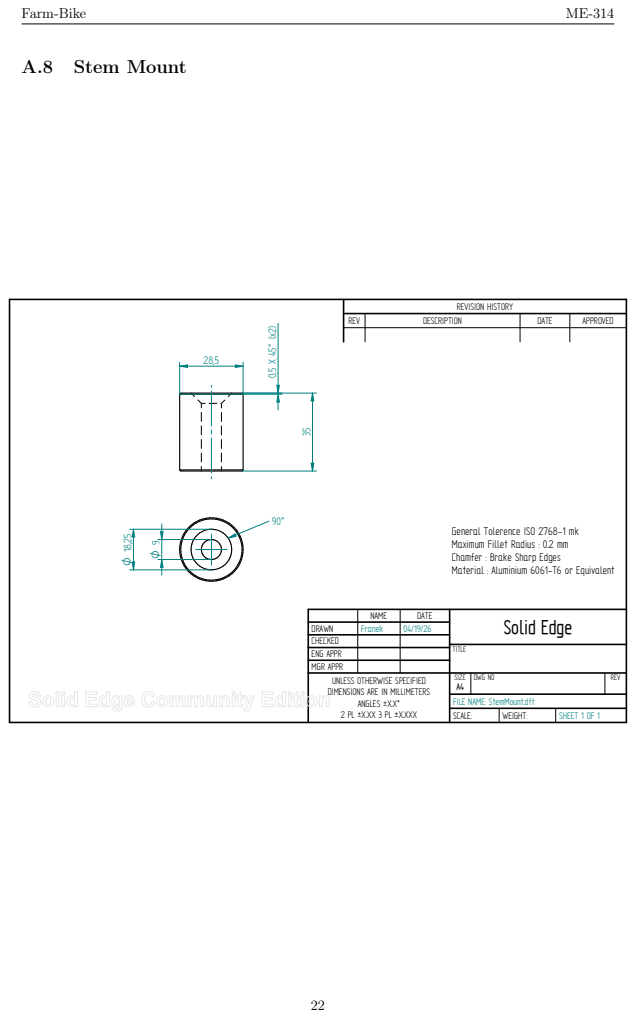
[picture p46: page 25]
SCALE:; WEIGHT:; SHEET 1 OF 1

REVISION HISTORY

REV | DESCRIPTION | DATE | APPROVED

General Tolerence ISO 2768-1 mk
Maximum Fillet Radius : 0.2 mm
Chamfer : Brake Sharp Edges
Material : Aluminium 6061-T6 or Equivalent

NAME | DATE | Solid Edge

DRAWN | Franek | 04/19/26
CHECKED
ENG APPR | | | TITLE
MGR APPR
UNLESS OTHERWISE SPECIFIED DIMENSIONS ARE IN MILLIMETERS ANGLES ±X.X° 2 PL ±X.XX 3 PL ±X.XXX | SIZE A4 | DWG NO | REV

FILE NAME: StemMount.dft

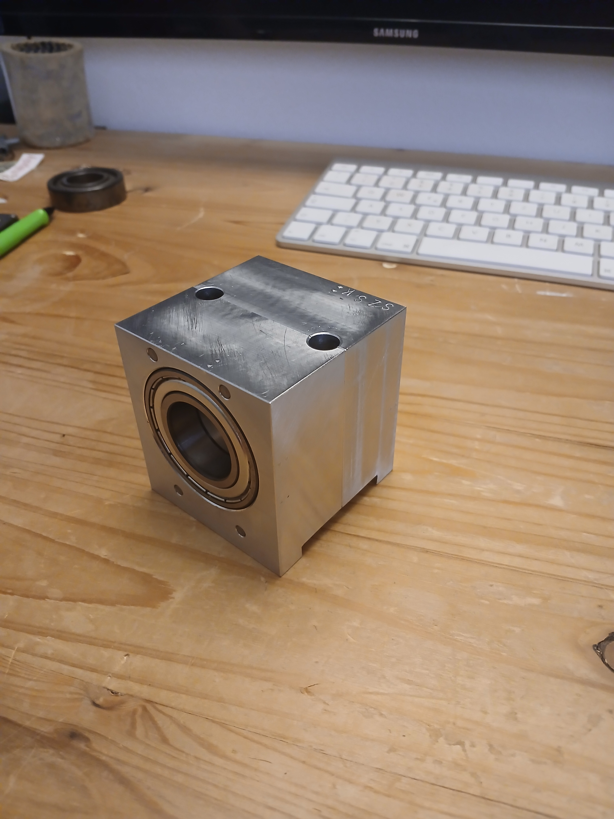
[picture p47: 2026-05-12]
Resources/PillowBlock5.jpg

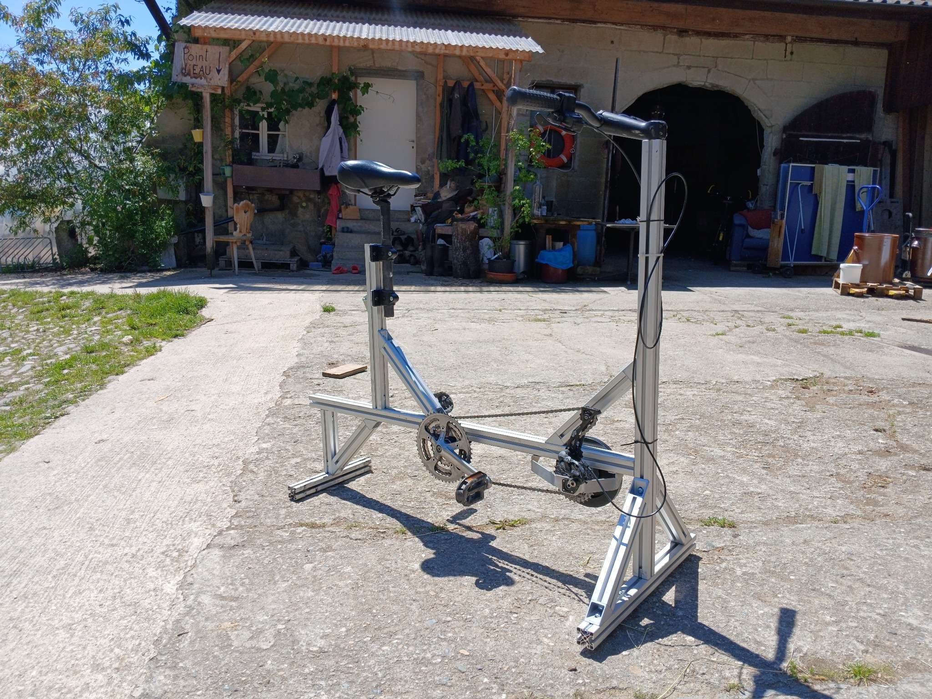
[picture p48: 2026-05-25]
Resources/PresentationPhoto0_compressed.jpg

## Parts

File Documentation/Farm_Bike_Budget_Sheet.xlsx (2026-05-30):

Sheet: Purchases
Farm-Bike Budget Sheet — Confirmed Purchases
Date | Supplier | Invoice / Receipt | Category | Reference | Item / Description | Qty | Total incl. VAT/shipping (CHF)
2026-03-31 | norelem Normelemente AG | 3210081379 | Belt & pulley transmission | 23200-0382522 | Taper-lock bushing 1108, 22.3×25, D=38, cast iron | 1 | 6.25
2026-03-31 | norelem Normelemente AG | 3210081379 | Belt & pulley transmission | 22070-12711 | V-belt pulley SPZ/10/Z, taper-lock, D=71, N=1, cast iron | 1 | 7.48
2026-03-31 | norelem Normelemente AG | 3210081379 | Belt & pulley transmission | 22070-11181 | V-belt pulley SPZ/10/Z, taper-lock, D=118, N=1, cast iron | 3 | 39.22
2026-03-31 | norelem Normelemente AG | 3210081379 | Belt & pulley transmission | 22071-12080 | V-belt DIN2215, type 10/Z, Li=2080, Br=10, neoprene | 1 | 20.74
2026-03-31 | norelem Normelemente AG | 3210081379 | Belt & pulley transmission | 23200-0572225 | Taper-lock bushing 1610, 25.4×22, D=57, cast iron | 1 | 9.01
2026-03-31 | norelem Normelemente AG | 3210081379 | Bearings & drivetrain support | 23800-102504712 | FAG deep-groove ball bearing 6005-2Z, 25×47×12 | 2 | 23.95
2026-03-31 | norelem Normelemente AG | 3210081379 | Keys, fasteners & mounting | 03288-08X45 | DIN6885 parallel key, form A, B=8, L=45, H=7 | 3 | 2.06
2026-03-31 | norelem Normelemente AG | 3210081379 | Adhesives & consumables | 97990-6030010 | Loctite 603 retaining compound, 10 ml | 1 | 27.1
2026-03-31 | norelem Normelemente AG | 3210081379 | Belt & pulley transmission | 23200-0571425 | Taper-lock bushing 1610, 25.4×14, D=57, cast iron | 2 | 18.03
2026-03-31 | norelem Normelemente AG | 3210081379 | Keys, fasteners & mounting | 29014-30 | Tube clamp/bracket, M=80, G=50, L=62.5, A=30 | 2 | 11.23
2026-03-31 | norelem Normelemente AG | 3210081379 | Keys, fasteners & mounting | 27616-08095 | Fixing support, form B long, zinc-plated steel, L=95, A=75 | 1 | 6.79
2026-04-13 | EPFL Point Vélo | Receipt 9900000288211 | Bicycle components |  | Second-hand bicycle material | 1 | 45
 |  |  |  |  |  |  | 216.86

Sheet: Dashboard
Farm-Bike Project Budget Summary
Metric | Value | Category | Subtotal excl. VAT | Total incl. VAT/shipping
Confirmed total paid (incl. VAT + shipping) | 0 | Belt & pulley transmission | 0 | 0
Norelem subtotal excl. VAT | 0 | Bearings & drivetrain support | 0 | 0
Norelem shipping | 28.95 | Keys, fasteners & mounting | 0 | 0
Norelem VAT | 12.88 | Adhesives & consumables | 0 | 0
Norelem total | 0 | Bicycle components | 0 | 0
Point Vélo total | 0
Number of purchase lines | 12 | TOTAL | 0 | 0
Scope note
This budget is based on the purchase evidence included in the uploaded project folder: the Norelem order confirmation and the EPFL Point Vélo receipt. Recovered parts, donated parts, off-cuts, Item profiles recovered from decommissioned machinery and workshop labour are listed separately and excluded from the confirmed paid total unless a price is added later.

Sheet: Recovered_or_Excluded
Recovered / In-kind / Not Priced Items
Category | Item | Source / evidence | Qty | Unit value estimate (CHF) | Total estimate (CHF) | Budget treatment
Frame structure | Item Profile 8 aluminium profiles and relevant hardware | Report/README: recovered from decommissioned machinery |  |  |  | Excluded from confirmed purchases
Stock material | 6061 aluminium billet/off-cuts for pillow block | Report/README: material off-cuts/scrapped parts used where possible |  |  |  | Excluded unless price is added
Stock material | S235 steel plate/off-cut for flywheel | Report: flywheel cut from 5 mm S235 structural steel off-cut |  |  |  | Excluded unless price is added
Bicycle frame donor | Donor bicycle frame with BSA bottom bracket shell | Report/README: recovered from donor frame | 1 |  |  | Excluded / recovered
Bicycle drivetrain | Cassette, derailleur, shifter, handlebars, stem, crankset, bottom bracket, seatpost, saddle | Report/README and Point Vélo receipt; detailed line split unavailable |  |  |  | Partly covered by Point Vélo lump-sum receipt
Workshop resources | Machining, TIG welding, laser cutting, assembly labour | Project fabrication work; no purchase evidence in folder |  |  |  | Excluded from material budget

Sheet: Sources
Source Documents Used
Source file | Supplier / document | Key amounts extracted | Notes
Documentation/Confirmation.de.commande.norelem.3210081379.-.Redacted.pdf | norelem order confirmation 3210081379, dated 2026-03-31 | Subtotal 130.03 CHF; shipping 28.95 CHF; VAT 12.88 CHF; total 171.86 CHF | Line items copied from order confirmation
Documentation/Facture point velo EPFL.JPG | EPFL Point Vélo receipt, dated 2026-04-13 | Net 41.63 CHF; VAT 3.37 CHF; total 45.00 CHF | Receipt only lists one lump-sum line: Divers Matériel occa
Documentation/Farm_Bike_may25th2026.pdf and README.md | Project report / README | Recovered parts and no-cost items identified | Used to separate confirmed purchases from in-kind materials

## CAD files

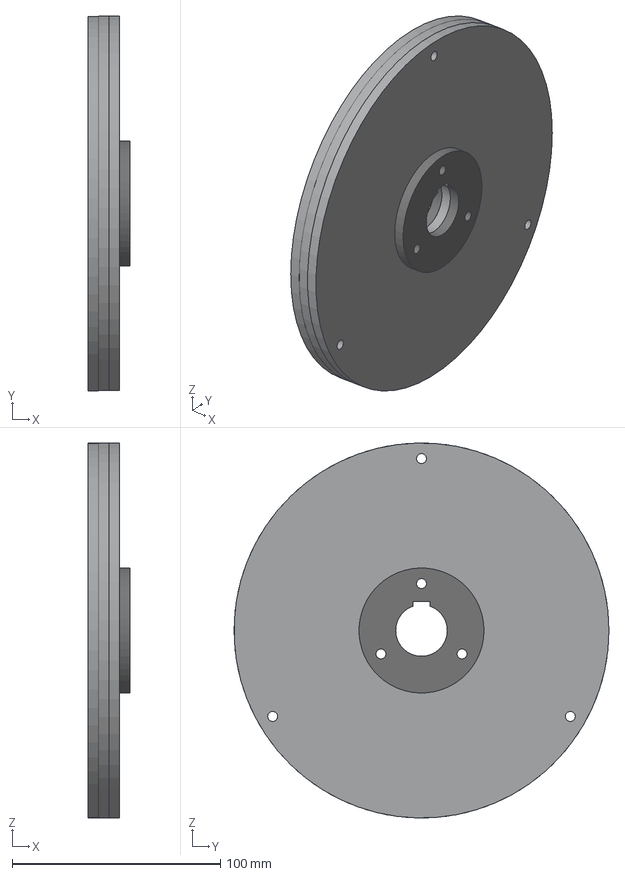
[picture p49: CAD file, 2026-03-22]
CadParts/FlyWheelAssy.stp
20.0 x 180.0 x 179.9 mm
FlyWheel
FlyWheelMass x 2
FlyWheelSpacer x 2

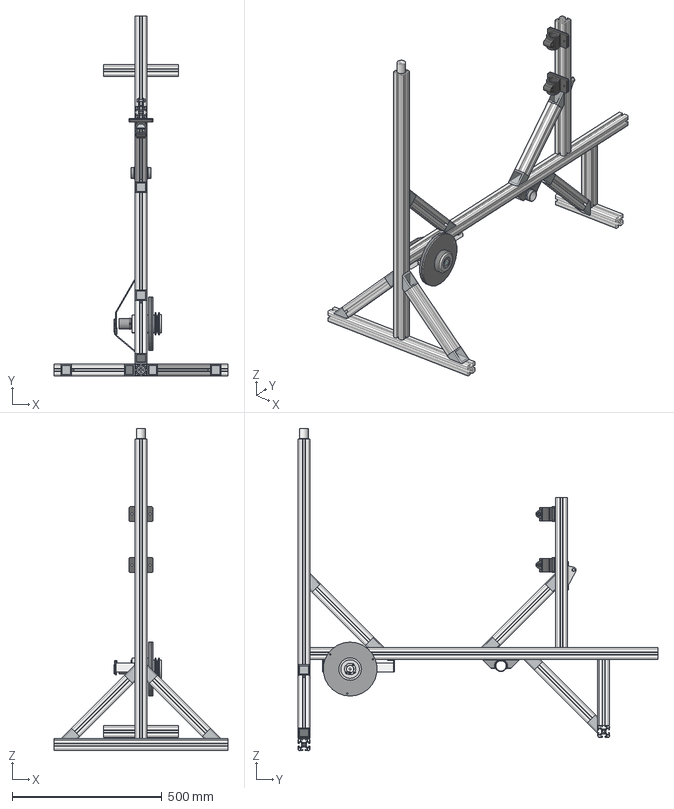
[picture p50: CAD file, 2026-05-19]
CadParts/FarmBike.stp
580.0 x 1200.0 x 1075.0 mm
HeadTube
MainFrame
FreeHubBody
45Joint x 10
FrontSupport x 6
FrontLeg
DerailleurBracket
TubeClampMount x 2
6005-2Z x 2
PillowBlock x 2
StemMount
BackSupport
BottomBracketMount
BottomBracketShell
FilletWeld_1
DerailleurHanger.psm
SeatTube
FlyWheel
FlyWheelMass x 2
FlyWheelSpacer x 2
DriveAxle
DummyBearing

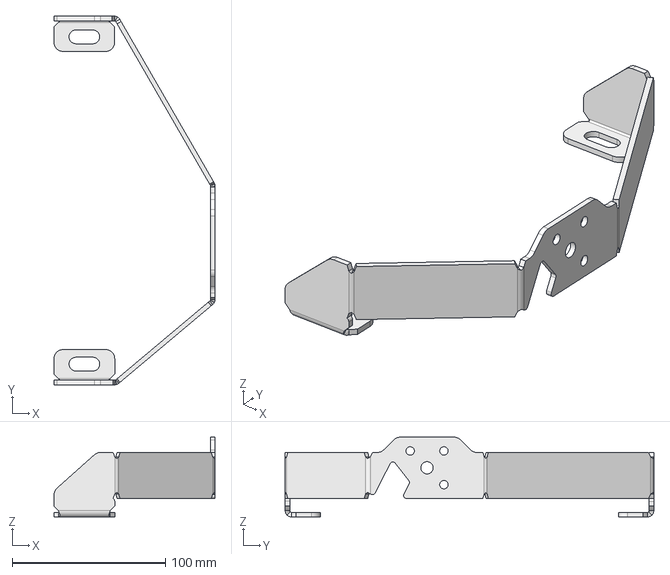
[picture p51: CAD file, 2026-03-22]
CadParts/DerailleurBracket.stp
105.0 x 240.4 x 52.0 mm

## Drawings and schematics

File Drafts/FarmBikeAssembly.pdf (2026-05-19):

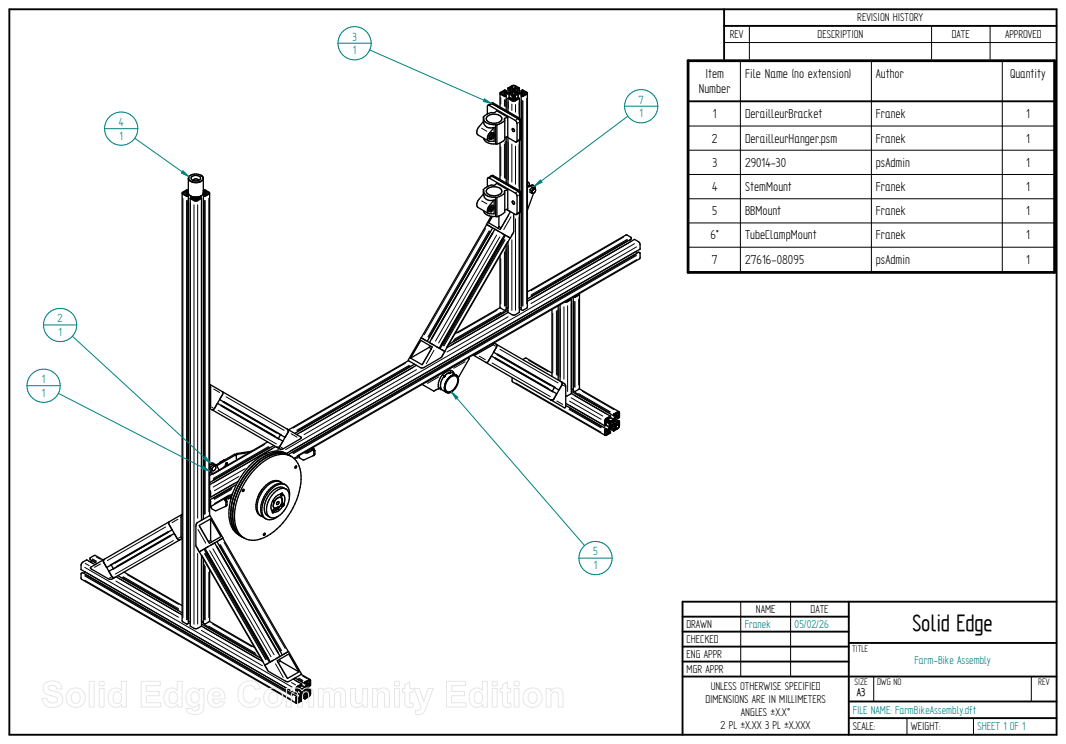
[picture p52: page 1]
TITLE; SCALE:; WEIGHT:; SHEET 1 OF 1

REVISION HISTORY

REV | DESCRIPTION | DATE | APPROVED

Item Number | File Name (no extension) | Author | Quantity

1 | DerailleurBracket | Franek | 1
2 | DerailleurHanger.psm | Franek | 1
3 | 29014-30 | psAdmin | 1
4 | StemMount | Franek | 1
5 | BBMount | Franek | 1
6* | TubeClampMount | Franek | 1
7 | 27616-08095 | psAdmin | 1

NAME | DATE | Solid Edge

DRAWN | Franek | 05/02/26
CHECKED
ENG APPR
MGR APPR
UNLESS OTHERWISE SPECIFIED DIMENSIONS ARE IN MILLIMETERS ANGLES ±X.X° 2 PL ±X.XX 3 PL ±X.XXX | SIZE A3 | DWG NO | REV

Farm-Bike Assembly

FILE NAME: FarmBikeAssembly.dft

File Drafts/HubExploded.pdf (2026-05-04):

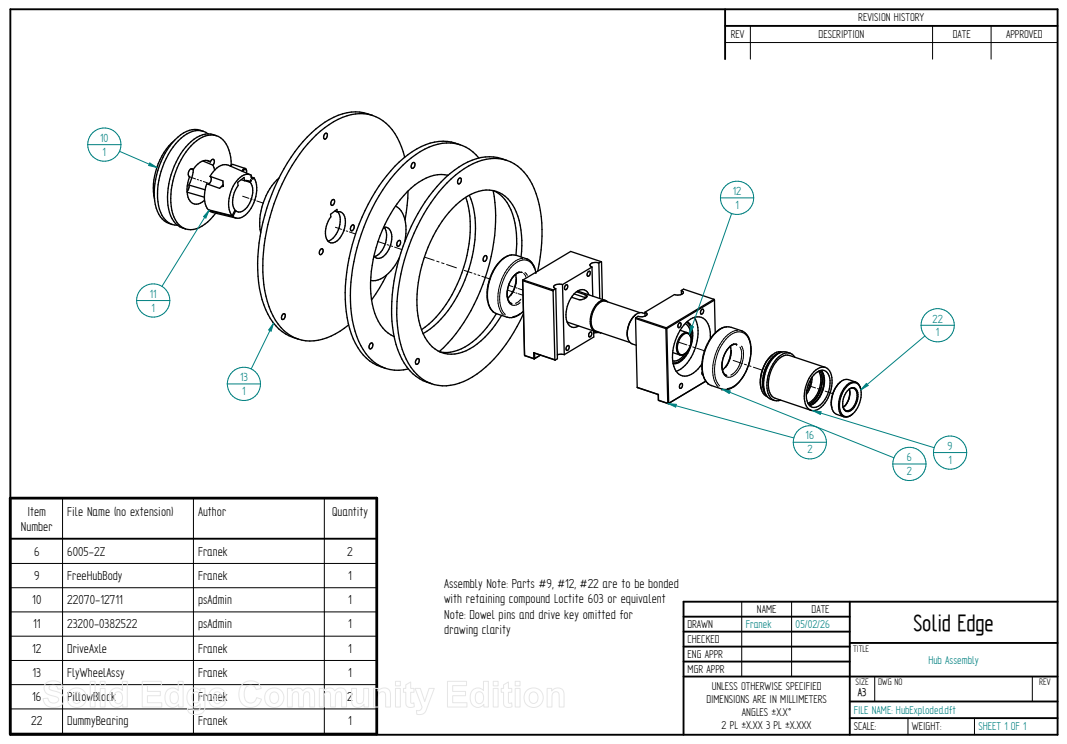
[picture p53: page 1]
TITLE; Hub Assembly; DWG NO; REV; FlyWheelAssy; Franek

REVISION HISTORY

REV | DESCRIPTION | DATE | APPROVED

Item Number | File Name (no extension) | Author | Quantity

6 | 6005-2Z | Franek | 2
9 | FreeHubBody | Franek | 1
10 | 22070-12711 | psAdmin | 1
11 | 23200-0382522 | psAdmin | 1
12 | DriveAxle | Franek | 1

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

NAME | DATE | Solid Edge

DRAWN | Franek | 05/02/26
CHECKED
ENG APPR

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

SIZE
FILE NAME: HubExploded.dft

16 | PillowBlock | Franek | 2
22 | DummyBearing | Franek | 1

SCALE: | WEIGHT: | SHEET 1 OF 1

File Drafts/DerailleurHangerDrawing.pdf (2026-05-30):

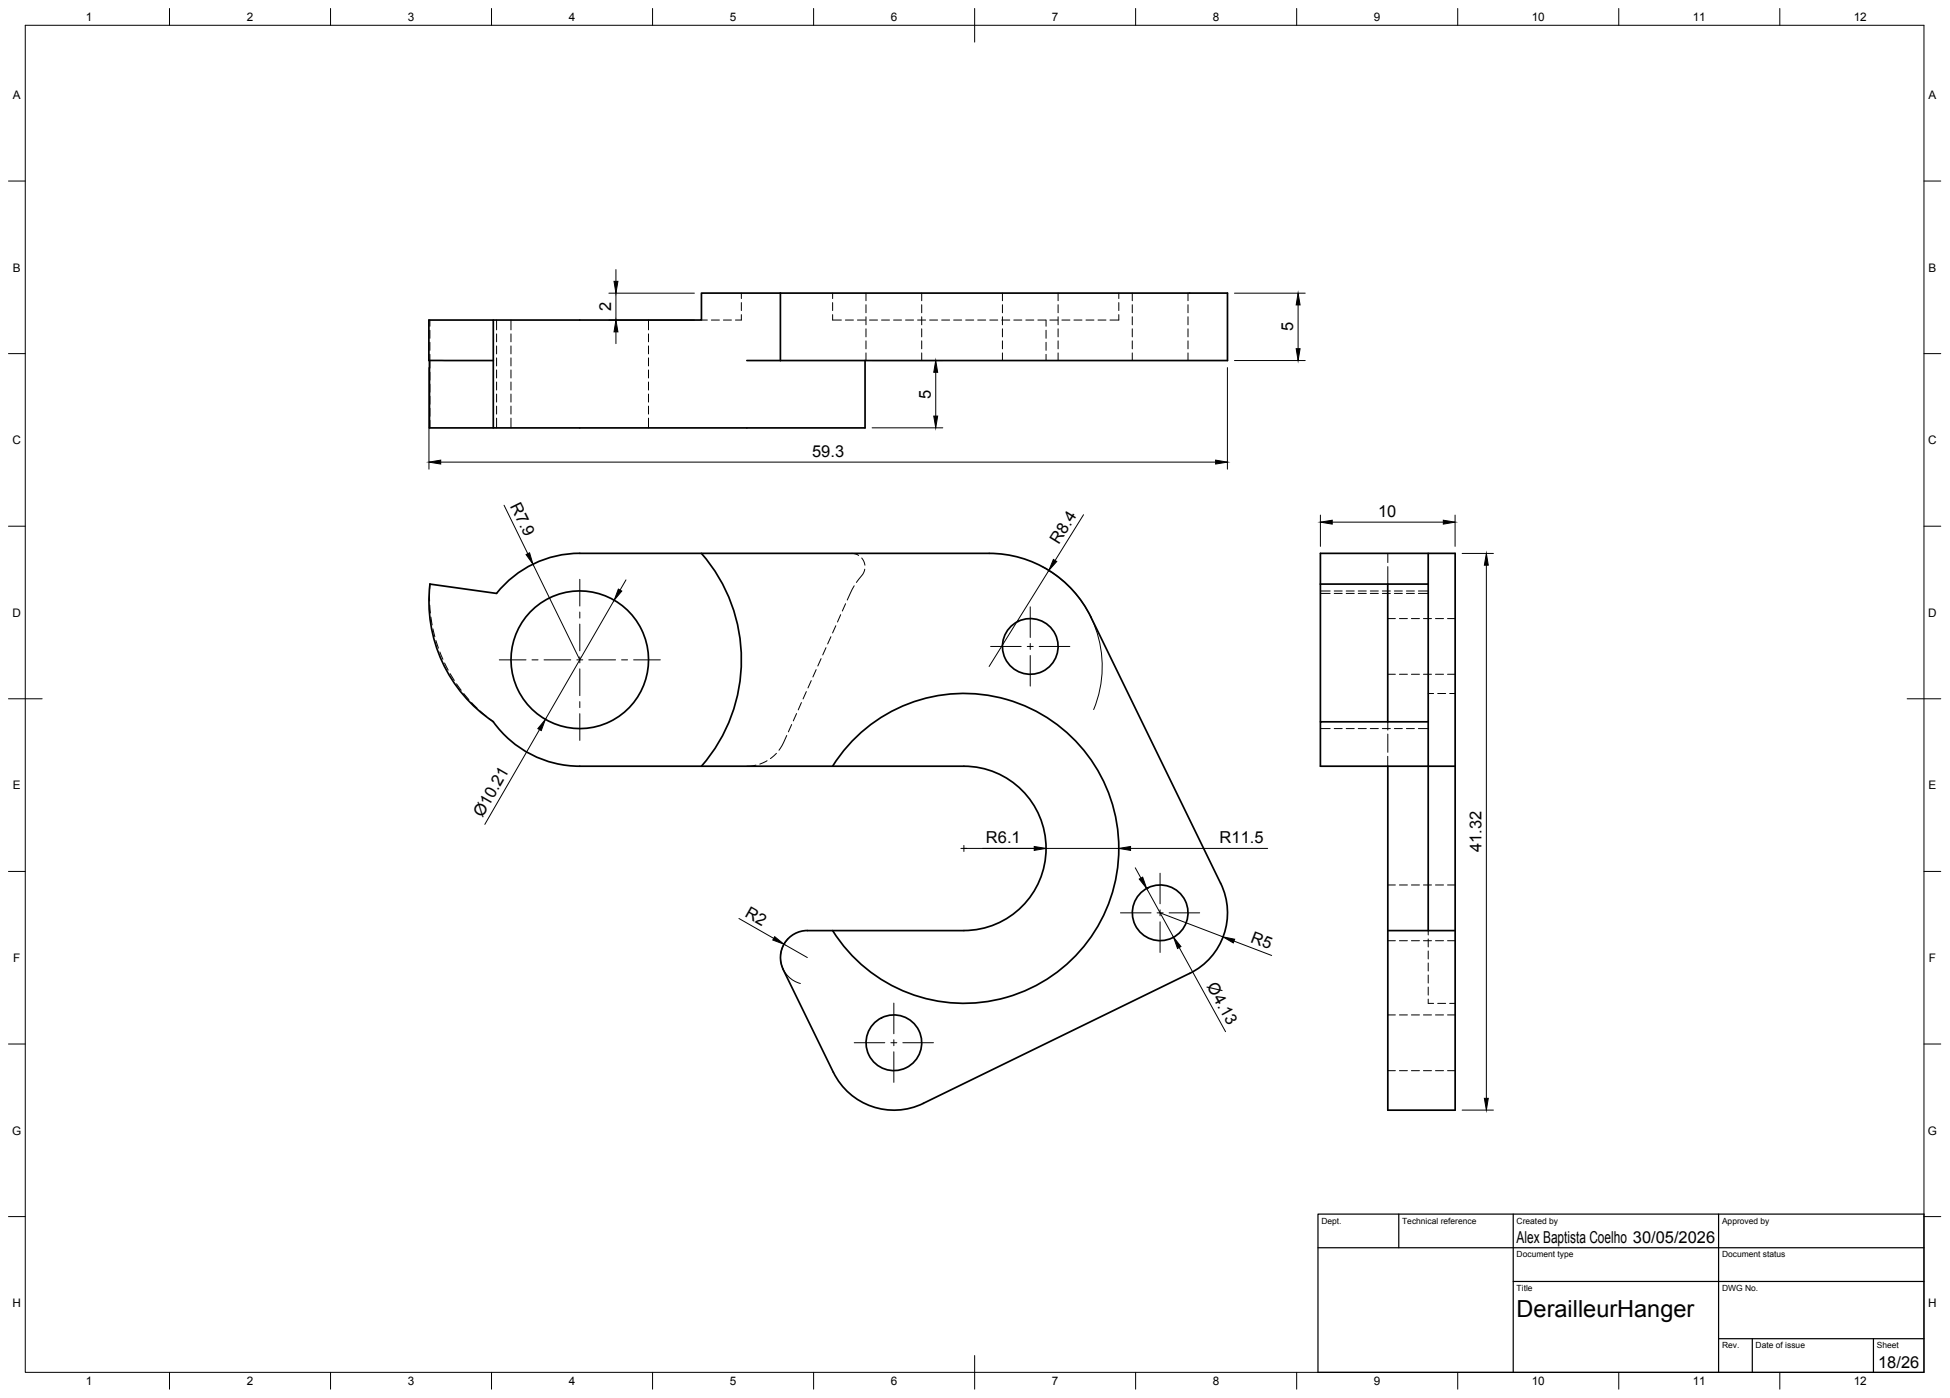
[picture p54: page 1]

Dept. | Technical reference | Created by Alex Baptista Coelho 30/05/2026 | Approved by

Document type | Document status

Title DerailleurHanger | DWG No.

Rev. | Date of issue | Sheet 18/26

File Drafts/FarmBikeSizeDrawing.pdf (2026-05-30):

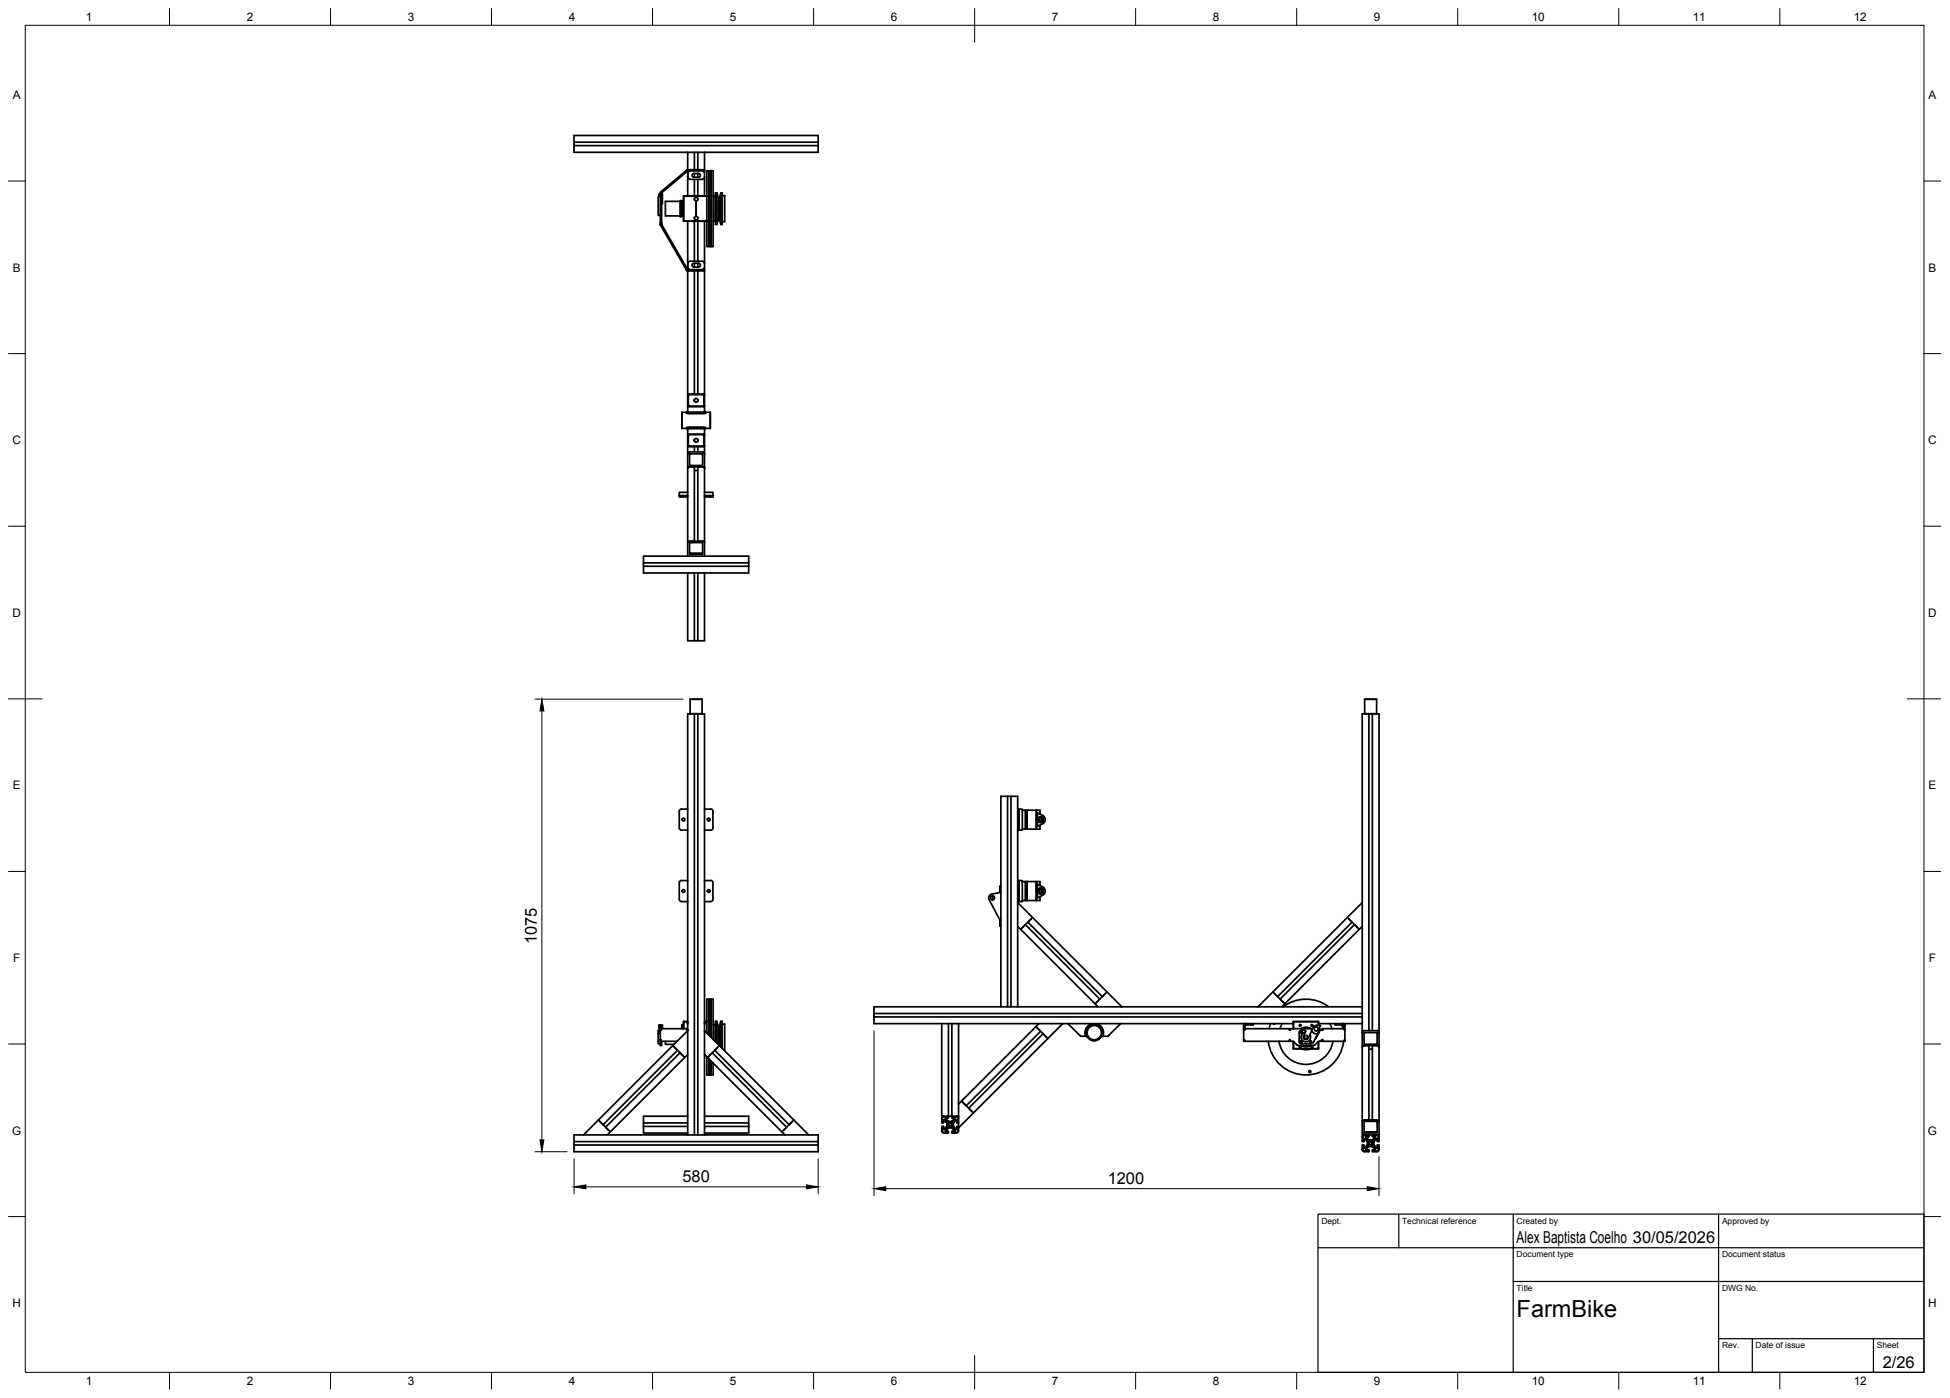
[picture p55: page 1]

Dept. | Technical reference | Created by Alex Baptista Coelho 30/05/2026 | Approved by

Document type | Document status

Title FarmBike | DWG No.

Rev. | Date of issue | Sheet 2/26

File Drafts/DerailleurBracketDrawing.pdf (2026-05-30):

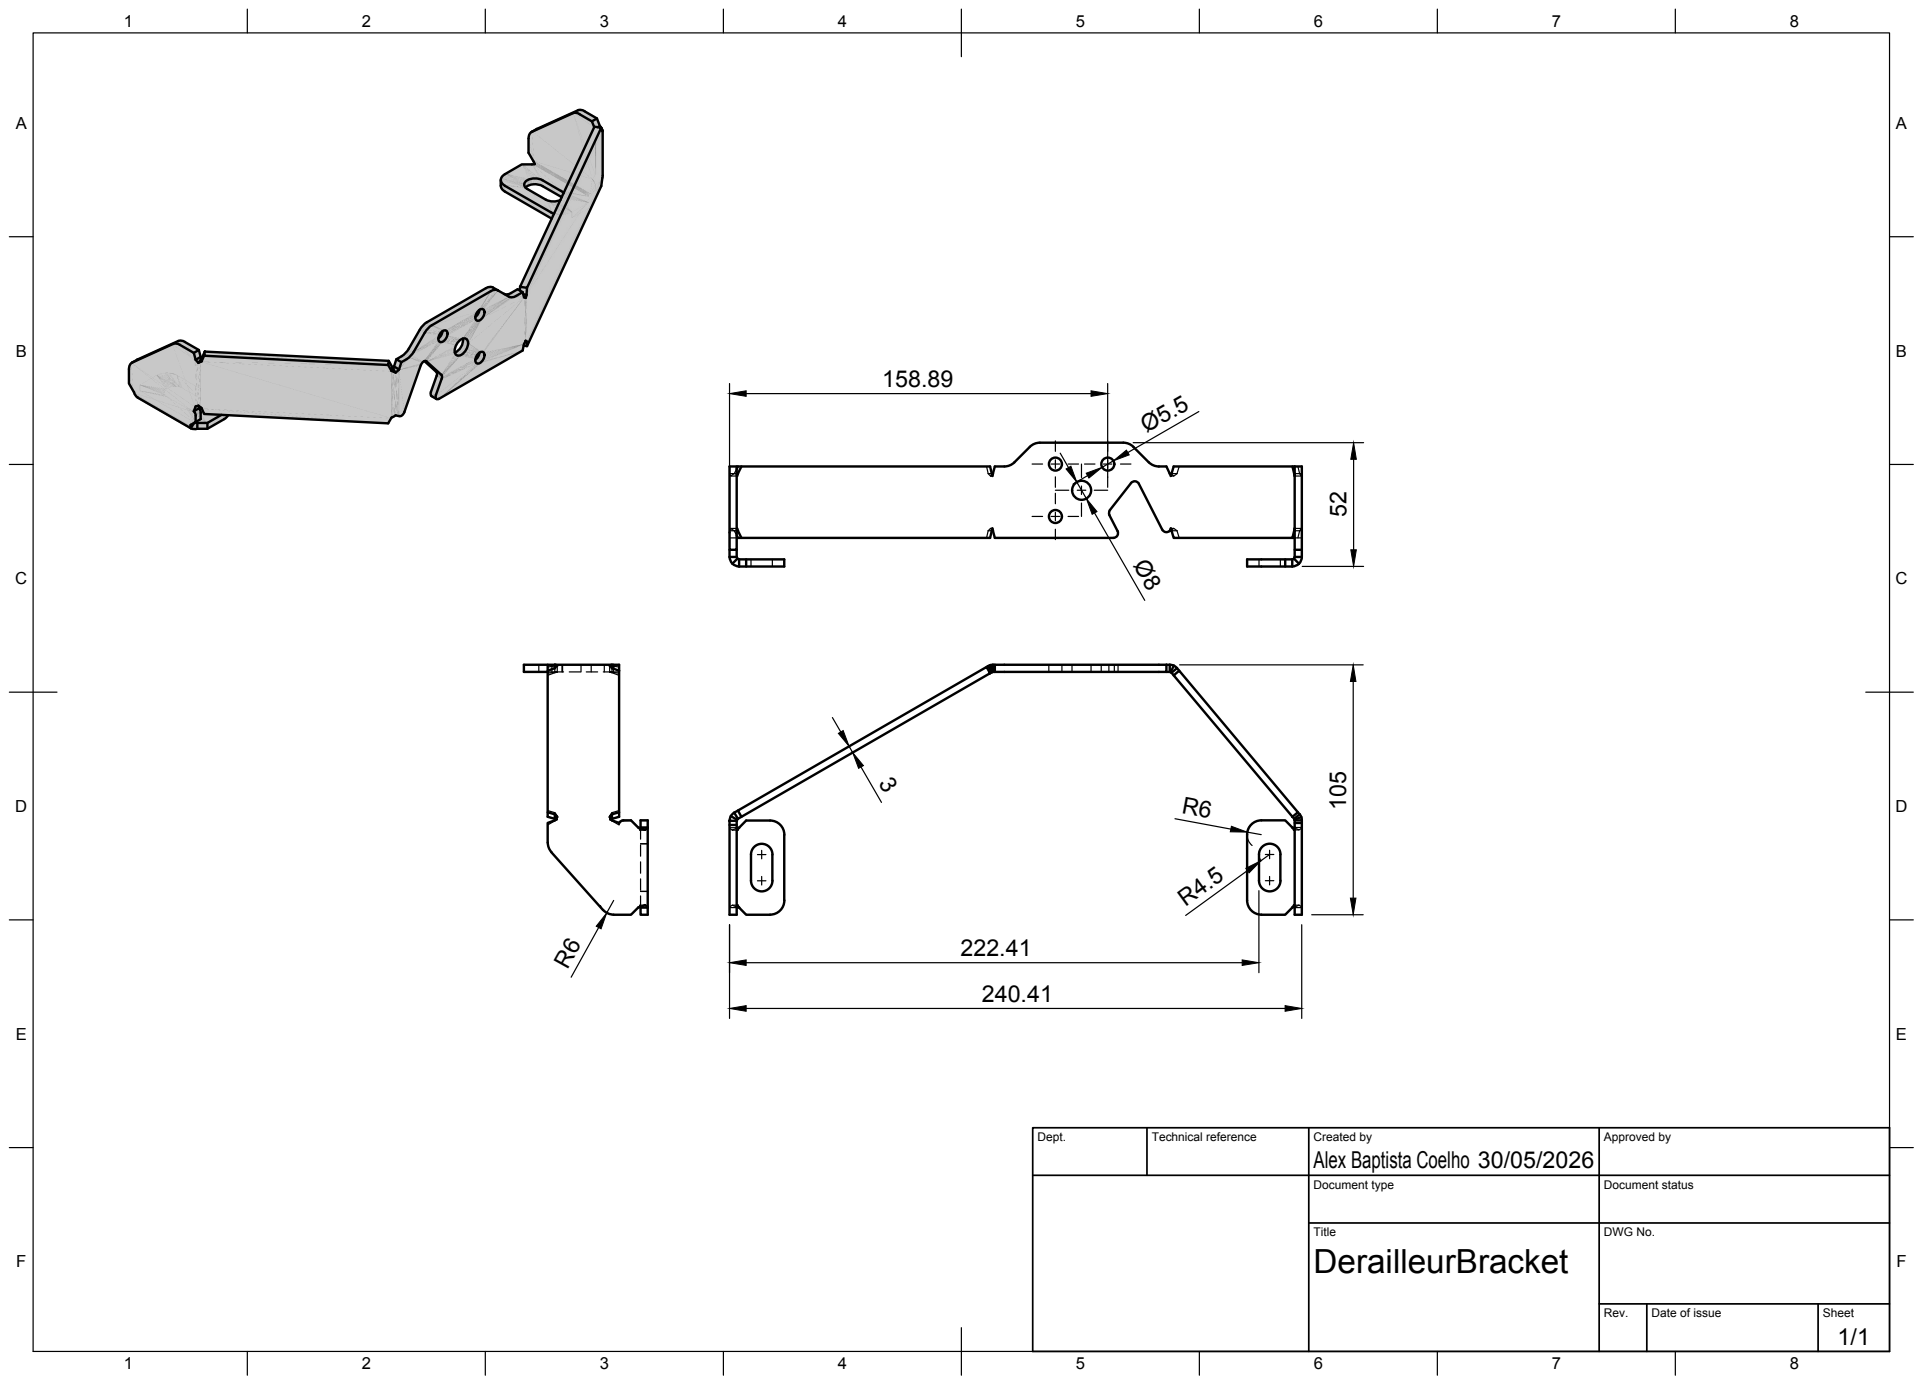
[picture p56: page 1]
Title; DWG No.; Rev.; Date of issue; Sheet

Dept. | Technical reference | Created by Alex Baptista Coelho 30/05/2026 | Approved by

Document type | Document status

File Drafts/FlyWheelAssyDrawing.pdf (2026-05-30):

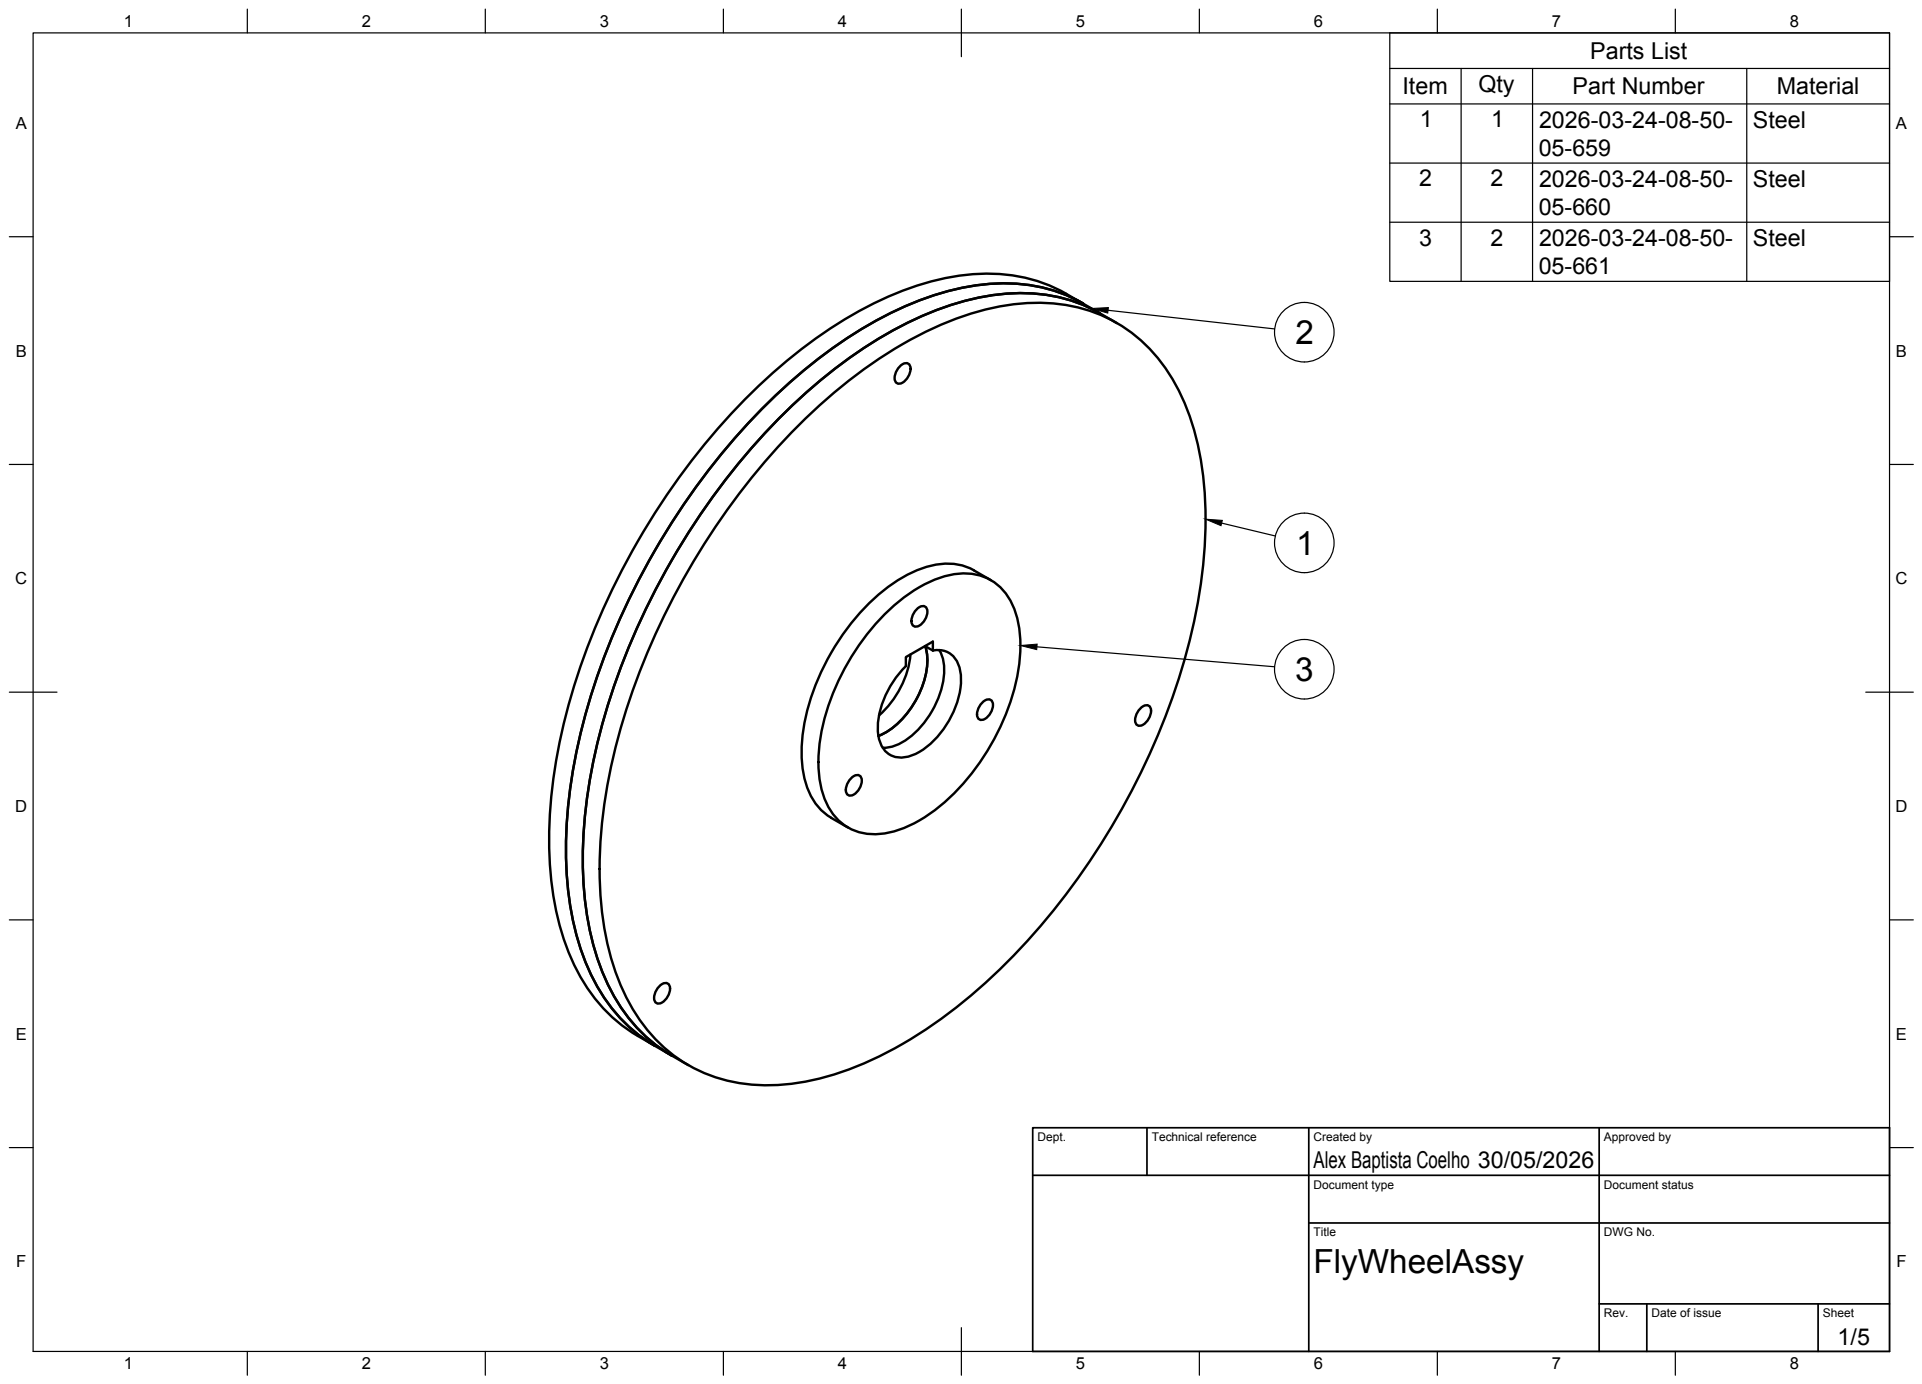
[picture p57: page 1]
Title; DWG No.; Rev.; Date of issue; Sheet; Parts List

Item | Qty | Part Number | Material
1 | 1 | 2026-03-24-08-50-05-659 | Steel

2 | 2 | 2026-03-24-08-50-05-660 | Steel

3 | 2 | 2026-03-24-08-50-05-661 | Steel

Dept. | Technical reference | Created by Alex Baptista Coelho 30/05/2026 | Approved by

Document type | Document status

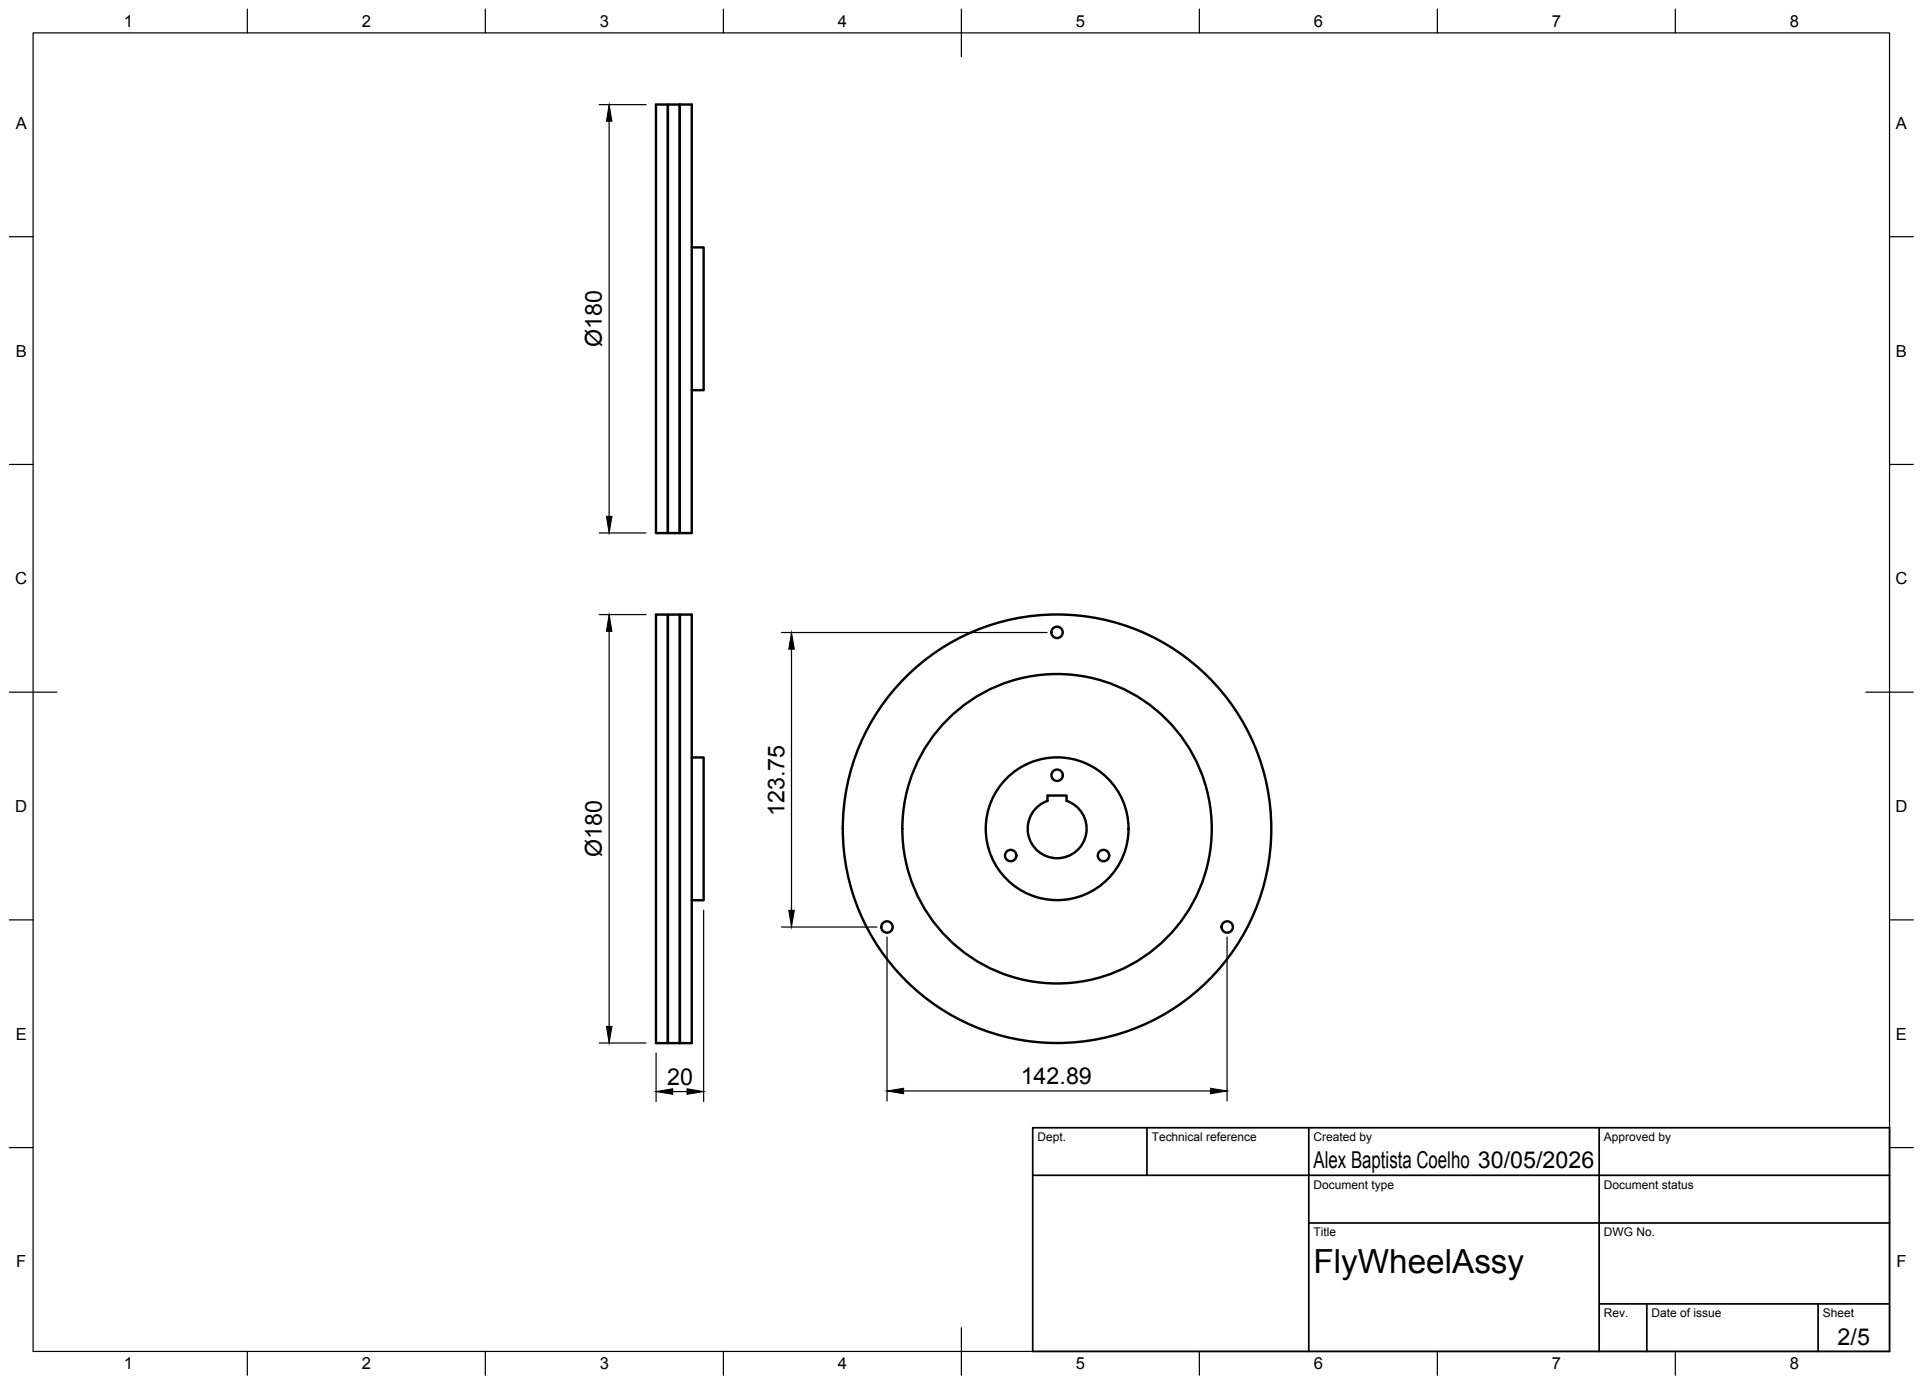
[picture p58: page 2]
Title; DWG No.

Alex Baptista Coelho Ø180 Ø180

Dept. | Technical reference | Created by 30/05/2026 | Approved by

Document type | Document status

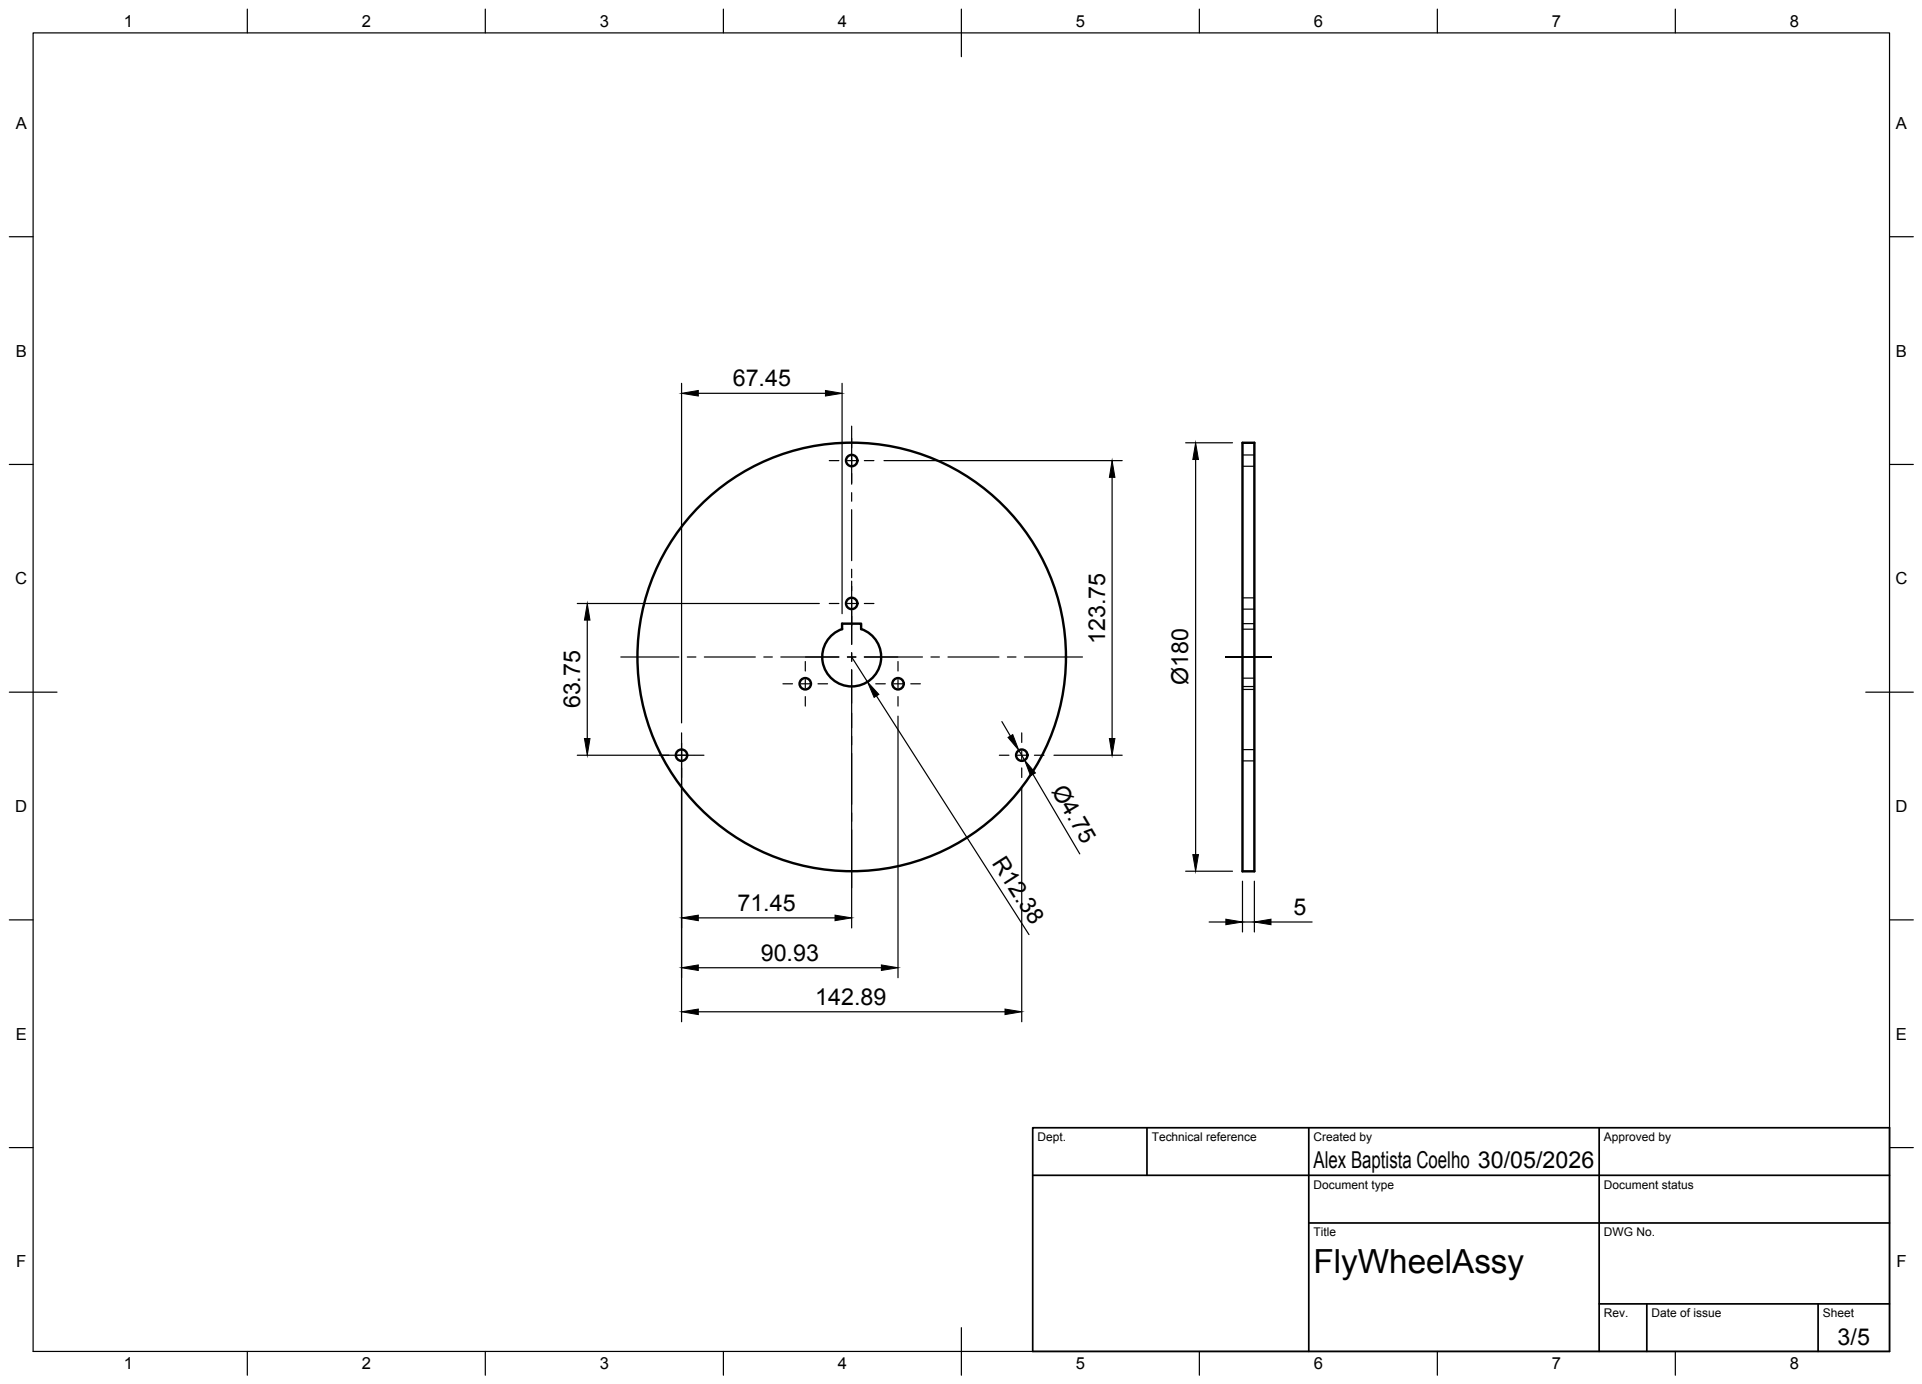
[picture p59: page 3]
Title; DWG No.

Dept. | Technical reference | Created by Alex Baptista Coelho 30/05/2026 | Approved by

Document type | Document status

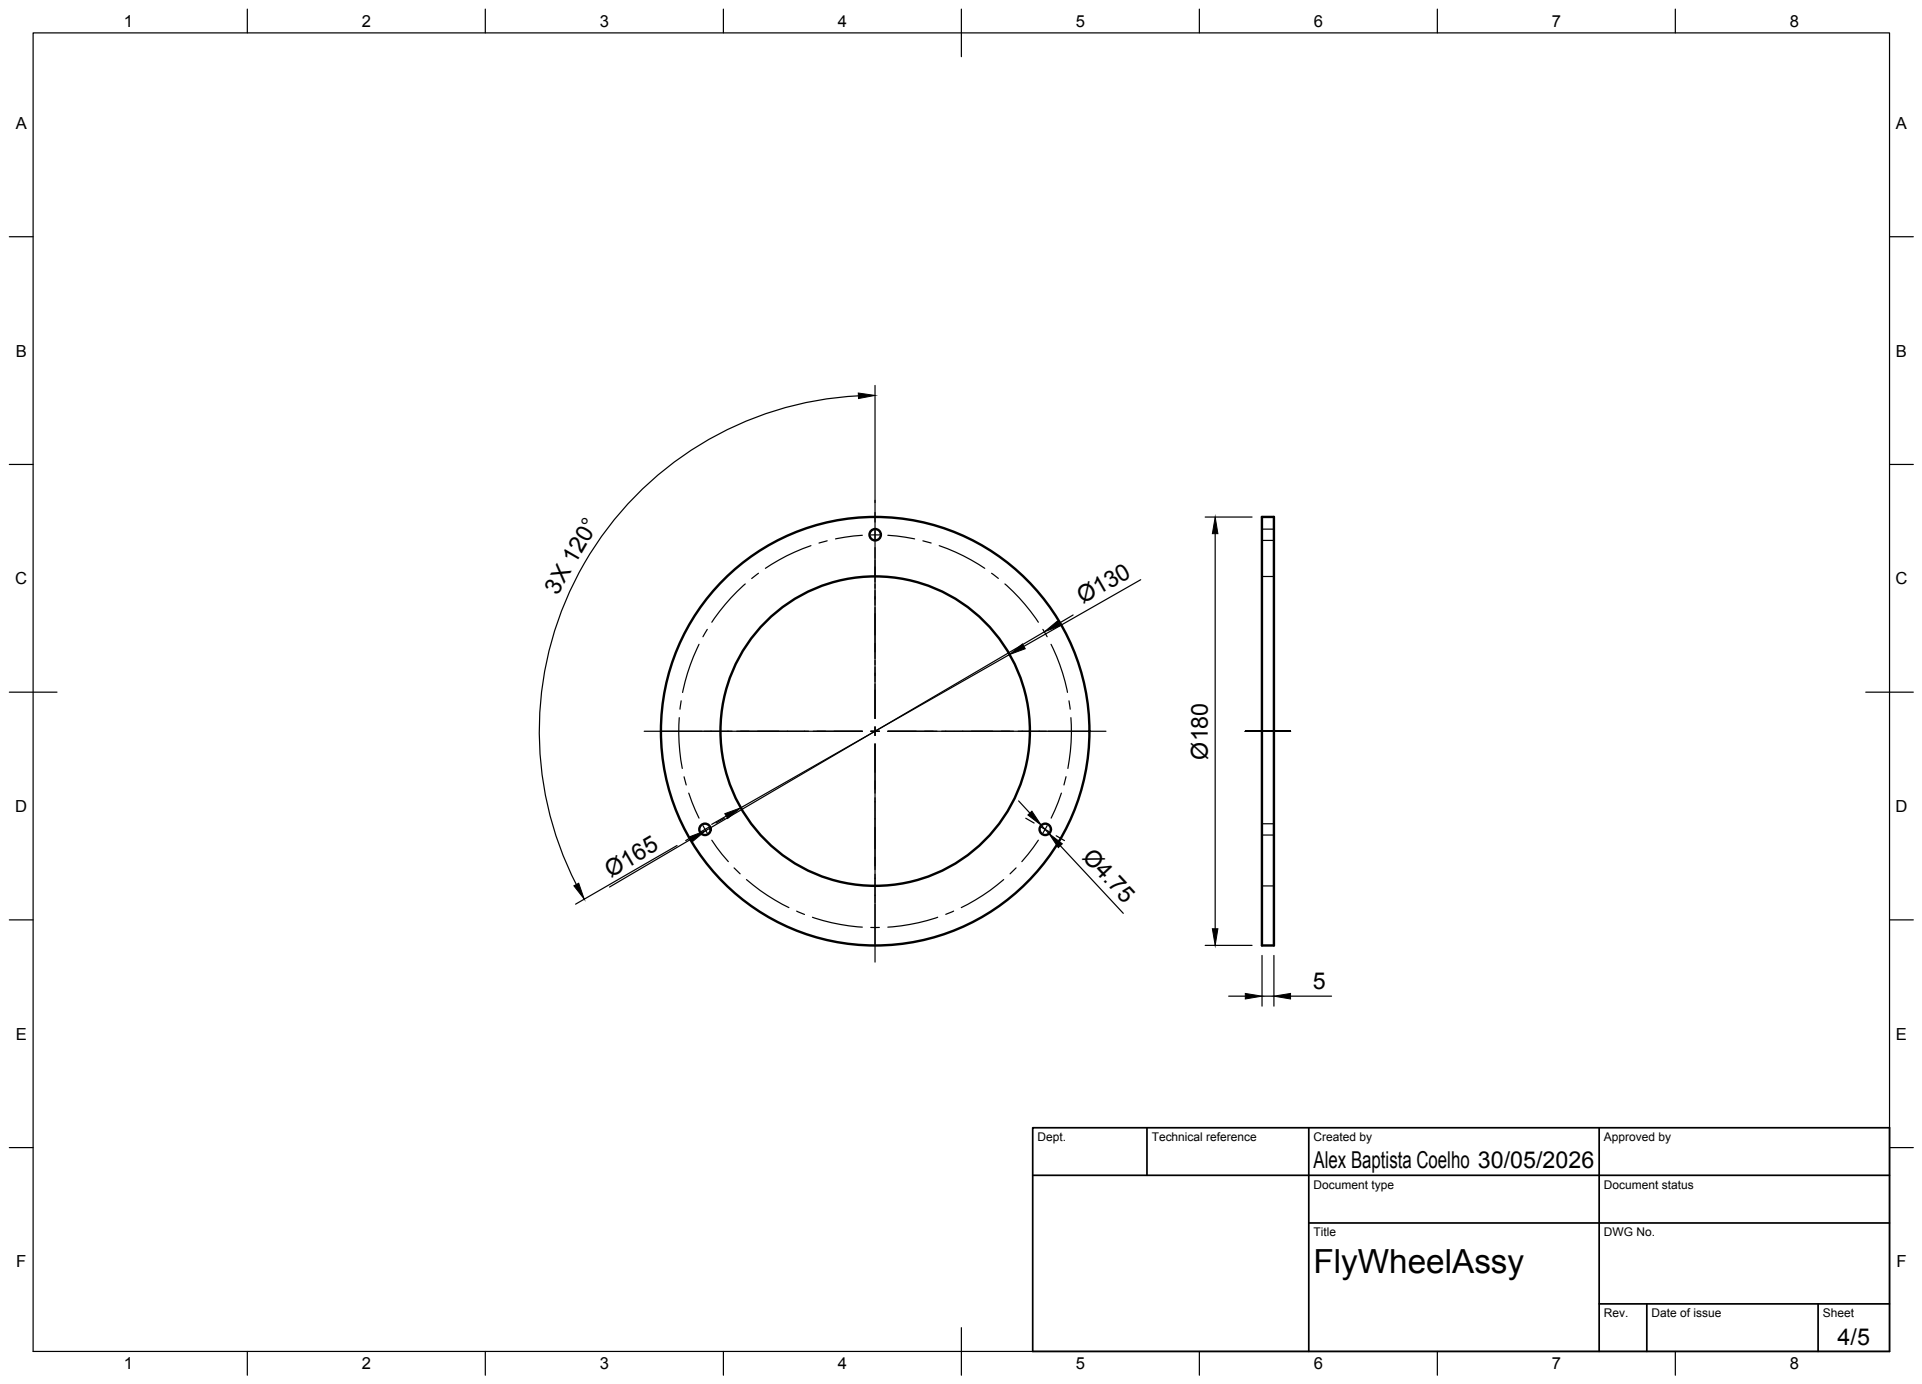
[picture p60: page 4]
Title; DWG No.

Alex Baptista Coelho Ø180

Dept. | Technical reference | Created by 30/05/2026 | Approved by

Document type | Document status

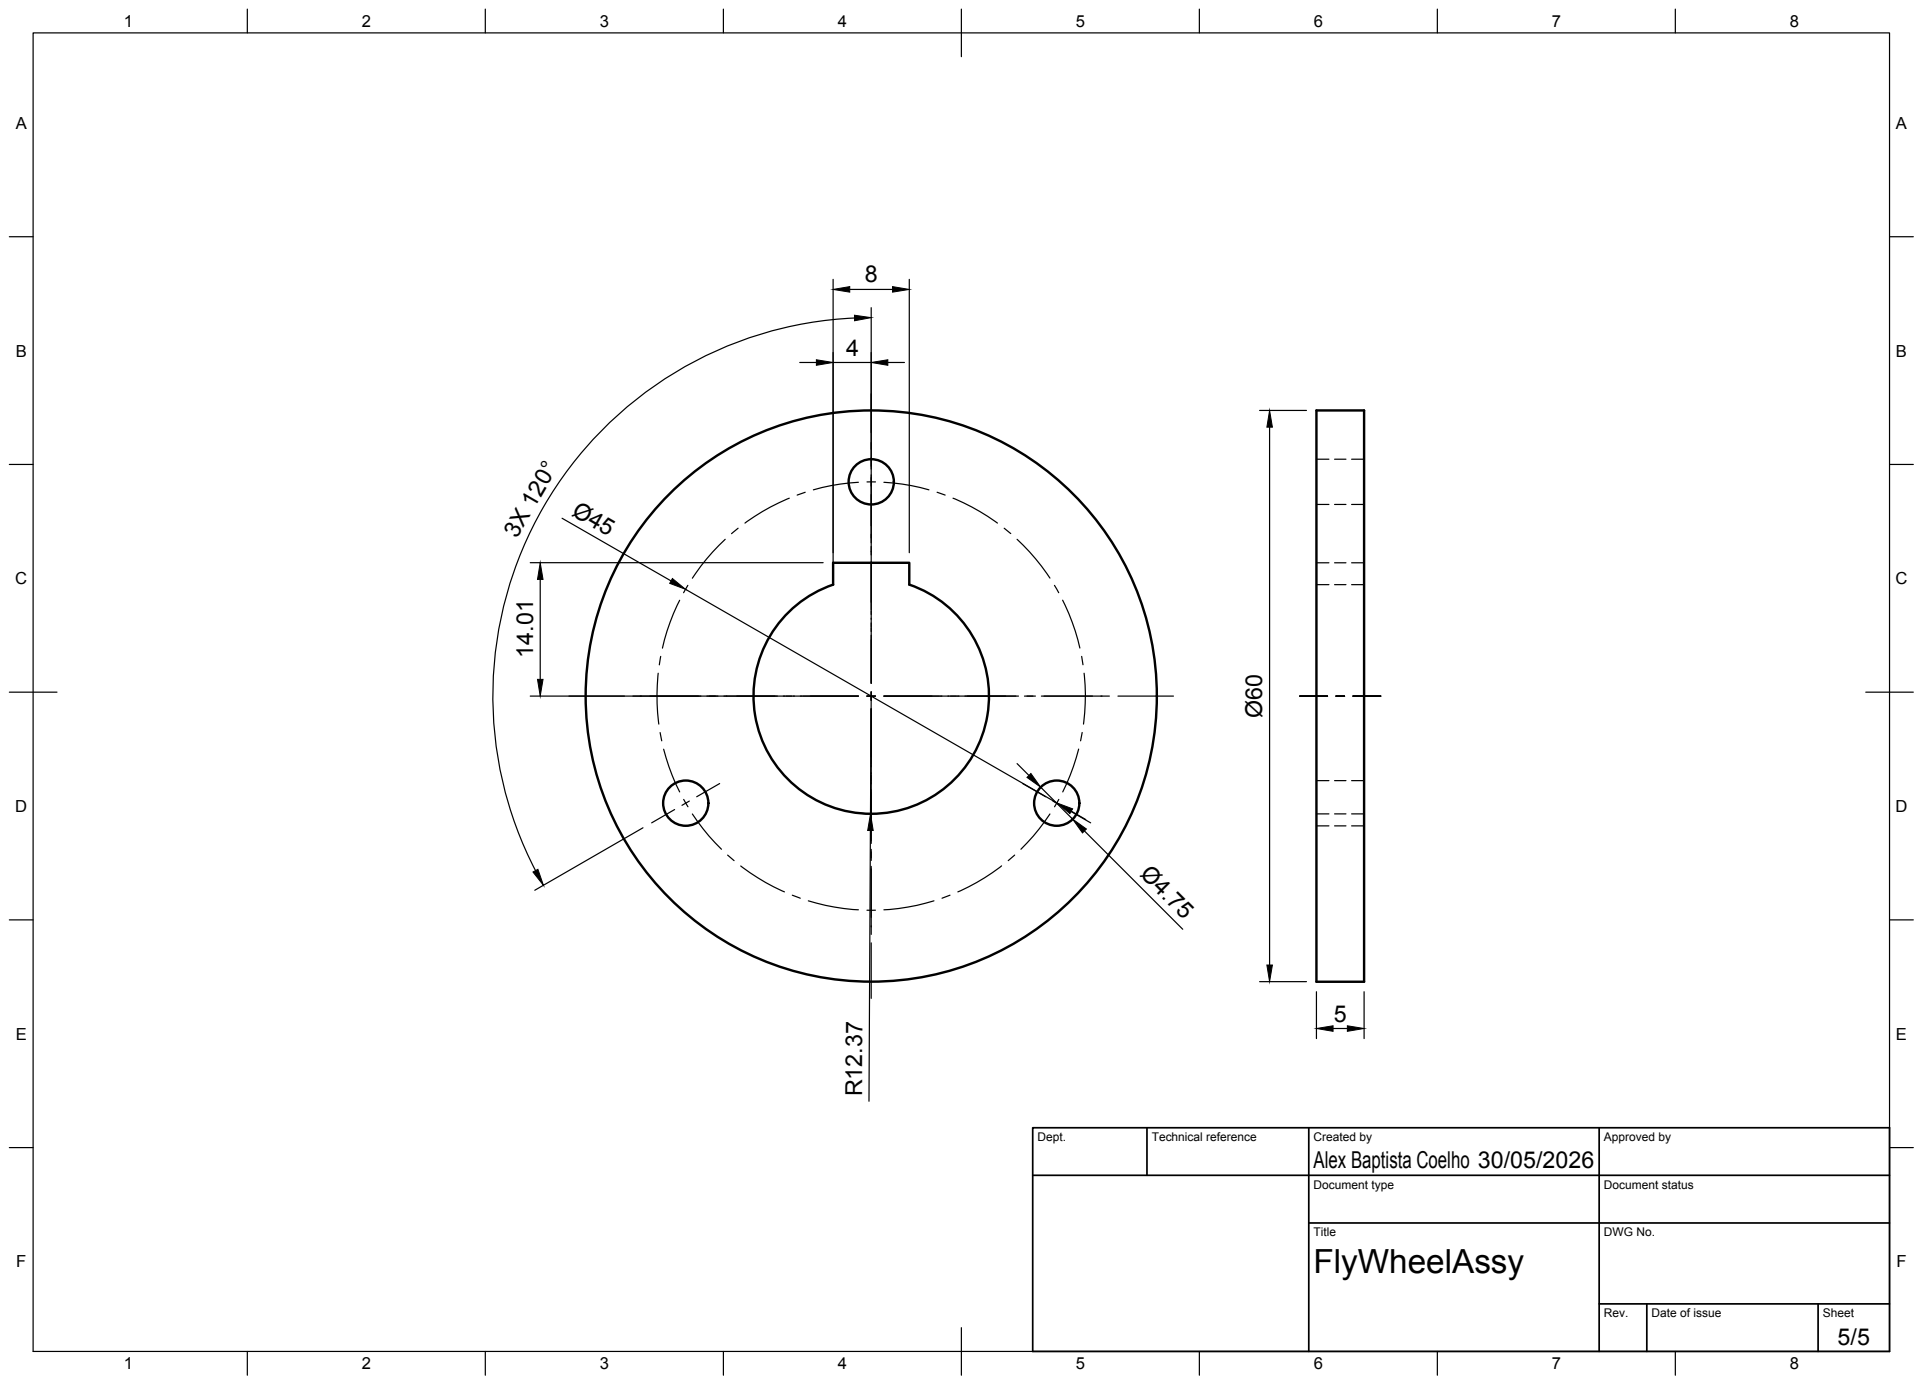
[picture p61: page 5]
Title; DWG No.

Dept. | Technical reference | Created by Alex Baptista Coelho 30/05/2026 | Approved by

Document type | Document status

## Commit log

2026-03-26 Transmission ratio calculation added
    [FarmBikeSpeedCalc.xlsx]
2026-03-30 Assembly of The FarmBike added
2026-04-06 Updated Cad Assembly
2026-04-19 Added StemMount & BBMount, Updated Cad Assembly
2026-05-01 Updated Cad Assembly after adding missing parts
2026-05-02 Finalized Cad Assembly and Added Assembly Drawings
    [FarmBike.stp]
2026-05-19 Updated CAD Assy for Modifications
    [FarmBike.stp]

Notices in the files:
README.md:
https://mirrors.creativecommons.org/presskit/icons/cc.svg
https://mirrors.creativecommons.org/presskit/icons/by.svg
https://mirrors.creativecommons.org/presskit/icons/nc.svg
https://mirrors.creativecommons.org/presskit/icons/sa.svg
